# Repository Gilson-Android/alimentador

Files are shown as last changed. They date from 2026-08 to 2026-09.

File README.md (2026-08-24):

# AquaFeeder ESP32-S3

Alimentador automático de aquário com **agenda de horários**, **acionamento manual
de qualquer lugar** e **câmera** para conferir se está tudo bem. Todas as peças
são impressas em 3D e o firmware roda num ESP32-S3.

### 📖 [Guia de montagem](https://gilson-android.github.io/alimentador/) · 🔌 [Referência da API](https://gilson-android.github.io/alimentador/api.html)

O site é o mesmo conteúdo desta documentação, mas navegável, com seletor de motor,
calculadora de dose, checklist de viagem e gerador de comandos da API.

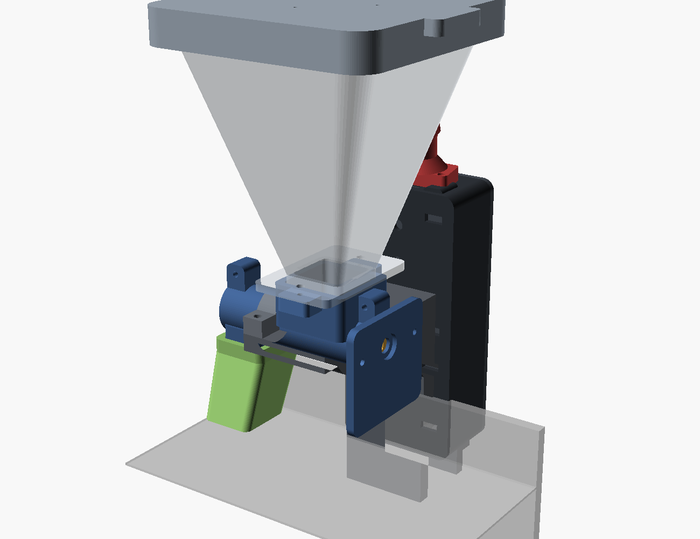
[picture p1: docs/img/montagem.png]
Vista de conjunto


## O que ele faz

| Recurso | Como |
|---|---|
| Agenda | Até 8 horários, dias da semana e porções por horário |
| Alimentar agora | Botão na interface web, comando no Telegram ou o botão BOOT da placa |
| Câmera | Foto sob demanda + vídeo ao vivo (MJPEG) na interface |
| Fora de casa | Bot do Telegram (`/alimentar`, `/foto`, `/status`) — sem abrir porta no roteador |
| Não perde refeição | Se faltar luz na hora marcada, recupera quando voltar (janela configurável) |
| Anti-entupimento | Recua a rosca antes de cada dose; sensor de grãos opcional avisa se nada caiu |
| Trava de segurança | Limite de porções por dia, por acionamento e intervalo mínimo |
| Atualização | OTA pela rede depois da primeira gravação |

## Como funciona a mecânica

Funil de ~300 ml → **rosca sem-fim (auger)** girada por um motor de passo
28BYJ-48 → a ração cai por uma calha inclinada acima da água.

Rosca sem-fim é o mecanismo certo aqui: a dose é proporcional ao ângulo de giro
(dá para dosar 0,2 ml), o tubo cheio de ração veda a passagem de umidade, e o
motor de passo trava sozinho quando parado. Uma volta completa entrega ~0,9 ml;
a porção padrão é **1/4 de volta ≈ 0,23 ml**, ajustável na interface.

> A rosca funciona muito bem com **ração granulada/peletizada de até ~3 mm**.
> Com ração em flocos grandes ela pode enroscar — quebre os flocos ou use
> granulado. Ver [docs/05-calibracao.md](docs/05-calibracao.md).

## Ver o projeto montado em 3D

Dois arquivos servem só para você olhar (**não são para imprimir**):

- `stl/montagem_completa.stl` — o conjunto inteiro já montado
- `stl/montagem_explodida.stl` — as peças separadas, para entender a ordem de montagem

Abra do jeito que preferir:

- duplo clique no Windows → abre no **Visualizador 3D**;
- arraste para o **Creality Print** (ou qualquer fatiador);
- ou jogue em https://viewstl.com, sem instalar nada.

Para girar as peças, esconder o funil, ver em corte ou explodido, abra
`cad/assembly.scad` no OpenSCAD e mexa nas chaves do topo do arquivo
(`CUTAWAY`, `EXPLODE`, `SHOW_HOPPER`, `SHOW_BOX`, `SHOW_TANK`).

| | |
|---|---|
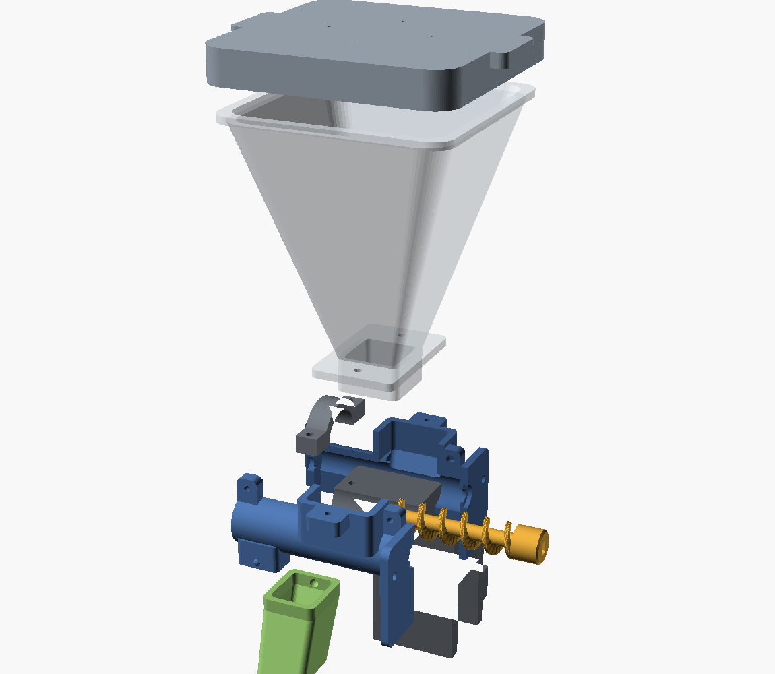
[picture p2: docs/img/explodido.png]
explodido
| montado |  |
| Montado no aquário | Explodido |
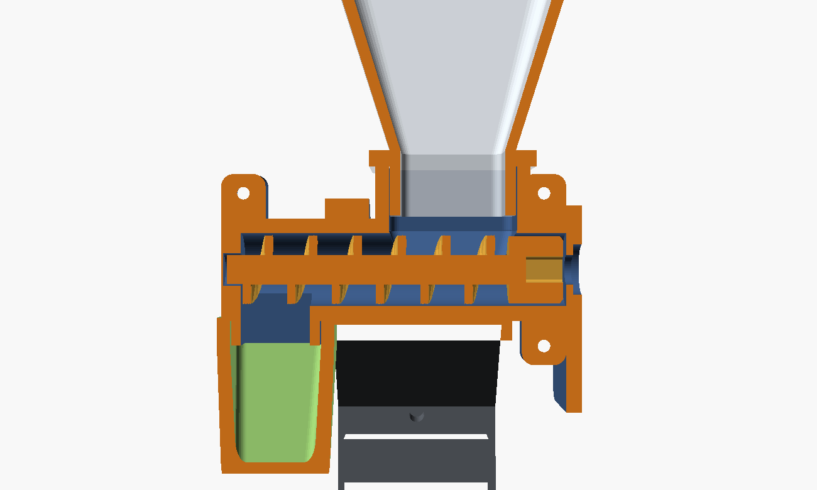
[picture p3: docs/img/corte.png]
corte
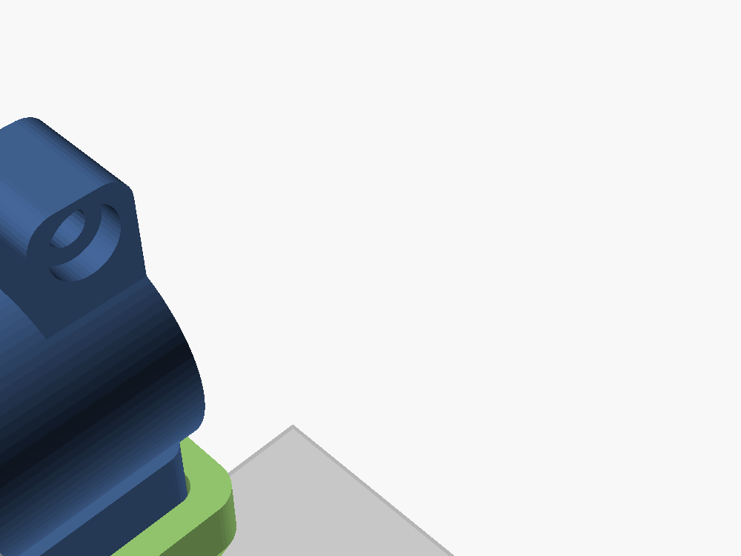
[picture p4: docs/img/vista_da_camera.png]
camera
|  |  |
| Corte no meio do tubo | O que a câmera enquadra |

## Lista de compras

| Item | Qtd | Preço aprox. (BRL) |
|---|---|---|
| Placa ESP32-S3 **com câmera** (kit Freenove ESP32-S3-WROOM CAM) | 1 | 90–170 |
| Motor 28BYJ-48 5 V + driver ULN2003 | 1 | 15–30 |
| Fonte 5 V / 2 A (ou carregador USB 5 V 2 A + cabo) | 1 | 25–45 |
| Capacitor eletrolítico 470–1000 µF / 10 V ou 16 V | 1 | 2 |
| Cabo 4 vias / jumpers fêmea-fêmea | ~1 m | 10 |
| Parafusos M3×8 (3), M3×10 (8), M3×12 (2), M3×16 (2), M4×12 (2), M2×6 (2) | — | 15 |
| Parafuso M4×30 + porca M4 (aperto da braçadeira) | 1 | 3 |
| Filamento **PETG** | ~270 g | 22 |
| *Opcional:* sensor óptico TCRT5000 ou par IR (confirma que caiu ração) | 1 | 8 |
| *Opcional:* sachê de sílica gel (anti-umidade dentro do funil) | 1 | 2 |

Total: **~R$ 190 a 300**, dependendo da placa.

Alternativas de placa que o firmware já suporta: **XIAO ESP32S3 Sense**
(menorzinha, câmera embutida) e **qualquer ESP32-S3 sem câmera** (compila com
`-e s3_sem_camera`).

## Ordem de execução

**Comece pelo [roteiro das 9 etapas](docs/00-etapas.md).** Ele é a ordem de
execução com um teste objetivo no fim de cada etapa — não passe para a próxima
sem o visto. A câmera é a última de propósito: é a única parte que, se não
funcionar, não impede o alimentador de alimentar.

Os arquivos abaixo são a referência por assunto, para consultar dentro de cada etapa:

1. **[Imprimir](docs/01-impressao.md)** — comece pela peça de teste (`peca_de_teste.stl`, ~10 min).
   Só depois imprima o resto.
2. **[Eletrônica](docs/02-eletronica.md)** — 6 fios, nada de solda obrigatória.
3. **[Montagem](docs/03-montagem.md)** — parafusar as duas metades do tubo, funil, calha, braçadeira.
4. **[Firmware](docs/04-firmware.md)** — gravar, conectar no Wi-Fi, definir senha.
5. **[Calibração](docs/05-calibracao.md)** — descobrir quantos passos = a porção do *seu* peixe.
6. **[Telegram / acesso remoto](docs/06-remoto.md)** — para usar de fora de casa.
7. **[Antes de viajar](docs/07-antes-de-viajar.md)** — checklist. Leia mesmo.

Deu problema? **[docs/08-problemas.md](docs/08-problemas.md)** tem os sintomas
mais comuns (rosca travando, reset ao alimentar, câmera não inicializa,
horário errado) com a causa e a solução de cada um.

## Estrutura do projeto

```
Alimentador/
├── index.html      guia de montagem (GitHub Pages)
├── api.html        referência da API HTTP
├── cad/            fontes OpenSCAD (paramétricas) + build.sh
├── stl/            STLs prontos para fatiar
│   ├── motor_28byj/    tubo + rosca para o 28BYJ-48
│   └── motor_nema17/   tubo + rosca para o NEMA 17
├── firmware/
│   ├── src/ include/   código C++ (PlatformIO)
│   └── bin/            binários já compilados
└── docs/           documentação em markdown + imagens
```

O firmware compila limpo em todos os ambientes (testado): RAM 17%, Flash 32%.

**CI:** `azure-pipelines.yml` compila o firmware nos 5 ambientes e renderiza todas
as peças no OpenSCAD a cada push — qualquer warning do OpenSCAD reprova o build.
Os `.bin` e os `.stl` saem como artefato. Para ligar: Azure DevOps → Pipelines →
New pipeline → GitHub → *Existing YAML* → `/azure-pipelines.yml`.

**Relatório das peças:** `python cad/dims.py` lista dimensões, volume e massa
estimada em PETG de cada peça, com o total por kit.

**Teste de encaixe:** `cad/check.sh` renderiza a interseção de cada par de peças
na posição de montagem e mede o volume. Volume zero = as peças só se tocam
(apoio, encaixe). Volume maior que zero = ocupam o mesmo espaço e não montam.
Foi assim que apareceram duas colisões que passavam batido no olho: as orelhas
do colar contra o chanfro do funil, e a calha batendo 0,6 mm na barriga do tubo.

Para mudar qualquer medida, edite `cad/common.scad` e rode `cad/build.sh` —
todos os STLs são regerados. Precisa do [OpenSCAD](https://openscad.org) instalado.

## Avisos importantes

- **Comida em excesso mata mais peixe que fome.** A maioria dos peixes
  tropicais adultos passa 5–7 dias sem comer sem problema nenhum. Prefira
  errar para baixo. A trava de porções/dia existe por isso.
- Teste o conjunto **por uma semana inteira** antes de depender dele numa viagem.
- Eletrônica fica **do lado de fora do aquário**, com laço de gotejamento no
  cabo. Nunca use fonte de mais de 5 V nem passe cabo por dentro da água.
- Ração absorve umidade e empedra: sachê de sílica no funil e tampa sempre fechada.

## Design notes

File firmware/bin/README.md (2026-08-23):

# Binários já compilados

Gerados com PlatformIO (espressif32 6.9.x / Arduino core 2.0.17) a partir do
código em `../src`. Servem para gravar sem instalar toolchain nenhum.

| Pasta | Placa |
|---|---|
| `freenove_s3_cam` | Freenove ESP32-S3-WROOM CAM (8 MB flash) — padrão |
| `xiao_s3_sense` | Seeed XIAO ESP32S3 Sense |
| `s3_sem_camera` | ESP32-S3 genérico, sem câmera |

O caminho recomendado continua sendo `pio run -t upload`
(ver [docs/04-firmware.md](../../docs/04-firmware.md)). Para gravar direto com esptool:

```bash
pip install esptool
cd freenove_s3_cam
esptool.py --chip esp32s3 --port COM5 --baud 921600 write_flash -z 0x0 bootloader.bin 0x8000 partitions.bin 0xe000 boot_app0.bin 0x10000 firmware.bin
```

Troque `COM5` pela porta da sua placa. Se der erro de conexão, ponha a placa em
modo download: segure BOOT, toque RESET, solte BOOT.

Depois de gravado, a configuração é toda pela interface web (modo AP no primeiro
boot: rede `AquaFeeder-XXXX`, senha `aquafeeder`, http://192.168.4.1).

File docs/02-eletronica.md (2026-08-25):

# 2. Eletrônica

> **Esquema visual colorido:** [guia no site → Eletrônica](https://gilson-android.github.io/alimentador/#eletronica).
> Lá tem o diagrama de ligação desenhado, com as cores de cada fio. Este arquivo é
> a versão em texto, para consultar offline.

O projeto suporta dois motores. Escolha a sua seção.

---

## Opção A — 28BYJ-48 + ULN2003 (5 V)

São 6 fios. Não precisa soldar nada se usar jumpers fêmea-fêmea.

```
      FONTE 5V 2A
        +5V  ────────────┬──────────────┬─────────┐
                         │              │         │
        GND  ────────┬───┼──────────┬───┼─────────┼──┐
                     │   │          │   │         │  │
                  ESP32-S3        ULN2003      C1 470–1000uF
                  5V   GND        5V   GND     (+)      (−)

   ESP32-S3 GPIO 1  ──────────────►  IN1   ULN2003
   ESP32-S3 GPIO 2  ──────────────►  IN2
   ESP32-S3 GPIO 41 ──────────────►  IN3
   ESP32-S3 GPIO 42 ──────────────►  IN4

   ULN2003 (conector branco 5 vias) ──► motor 28BYJ-48
   Câmera OV2640 ──► conector flat da própria placa
```

| ULN2003 | ESP32-S3 | Por quê |
|---|---|---|
| IN1 | GPIO 1 | |
| IN2 | GPIO 2 | |
| IN3 | GPIO 41 | |
| IN4 | GPIO 42 | |
| 5 V | +5 V da fonte | motor puxa até ~500 mA, não tire do 3V3 |
| GND | GND comum | **o GND da fonte, do ESP32 e do driver tem que ser o mesmo** |

Compile com `pio run -e freenove_s3_cam -t upload`.

---

## Opção B — NEMA 17 + DRV8825 (12 V)

```
   FONTE 12V ──┬── VMOT (driver) ── C 100uF entre VMOT e GND
               └── step-down 5V ──► ESP32-S3 (pino 5V)

   GND da fonte ──► GND do ESP32 ──► GND do driver   (tudo no mesmo GND)

   ESP32 GPIO 1  ──► STP         M0 ──┐
   ESP32 GPIO 2  ──► DIR         M1 ──┴─► 3V3   (1/8 de micropasso)
   ESP32 GPIO 41 ──► EN          M2 ────► GND
   ESP32 3V3     ──► RST + SLP
   1A + 2A ──► uma bobina do motor   (pinos vizinhos na placa)
   1B + 2B ──► a outra bobina
```

Os nomes abaixo são os da **serigrafia da placa** (o clone roxo da Pololu):

| Pino (serigrafia) | Ligar em | Observação |
|---|---|---|
| **STP** | GPIO 1 | é o STEP |
| **DIR** | GPIO 2 | |
| **EN** | GPIO 41 | ativo em nível baixo; o firmware solta o motor quando para |
| **M0**, **M1** | 3V3 do ESP32 | M2=0 M1=1 M0=1 → **1/8 de micropasso** |
| **M2** | GND | idem |
| **RST**, **SLP** | 3V3 do ESP32 | os dois; sem isso o driver fica em reset |
| **VMOT** + o **GND** vizinho | +12 V da fonte | **100 µF eletrolítico direto nesses dois pinos** |
| **GND** (o outro) | GND comum | mesmo GND do ESP32 e da fonte |
| **1A** + **2A** | uma bobina do motor | os dois pinos de cada bobina são **vizinhos** na placa |
| **1B** + **2B** | a outra bobina | |
| **FLT** | — | é o FAULT; deixe solto |

Os 4 pinos de motor ficam no meio daquela fileira, entre o par `VMOT`/`GND` e o
par `FLT`/`GND`. **Contando a partir do lado do `VMOT`**, a ordem é:

```
VMOT · GND · 2B · 1B · 1A · 2A · FLT · GND
              └──┬──┘   └──┬──┘
              bobina 1  bobina 2
```

Os dois pinos de cada bobina são vizinhos — é isso que faz o plugue do cabo
encaixar direto.

**O DRV8825 não tem pino VDD.** Diferente do A4988, ele gera a lógica dele
internamente a partir do VMOT — não existe fio de 3,3 V *alimentando* o driver. O
3V3 do ESP32 serve só para puxar M0, M1, RST e SLP para nível alto. Consequência:
**sem os 12 V o driver está morto**, mesmo com o ESP32 ligado.

### Limite de corrente — faça antes de ligar o motor

Com o motor **desconectado** e os 12 V ligados, meça a tensão entre o cursor do
trimpot e o GND:

- **DRV8825:** `Vref = corrente ÷ 2` → **0,25 V para 0,5 A**
- A4988: `Vref = corrente × 0,8` → 0,4 V para 0,5 A

0,4 a 0,6 A é mais que suficiente para a rosca e mantém o driver frio.

### O cabo que vem com o motor já resolve os pares

Os cabos de motor de impressora **trocam a ordem dos fios entre as duas pontas**,
de propósito:

| Ponta | Ordem | Pares |
|---|---|---|
| no motor (JST) | vermelho · preto · azul · verde | intercalados |
| no driver (plugue 4 vias) | vermelho · azul · verde · preto | **vizinhos** |

Como os 4 pinos de motor do DRV8825 também são vizinhos por par (`2B`+`1B` e
`1A`+`2A`), o plugue **encaixa direto nos 4 pinos em sequência**, sem separar fio
nenhum.

E tanto faz a orientação: plugado virado 180° os pares continuam certos (só troca
qual bobina é qual). A única diferença é o sentido de giro da rosca, que se
corrige em *Ajustes → Dosagem → Inverter sentido*, sem mexer em fio.

### Se o seu cabo for outro: achar os pares

Multímetro em continuidade (ou ohms) e toque dois fios do motor por vez. O par que
apitar — ou marcar 2 a 4 Ω — é uma bobina, e vai em **1A + 2A**. O outro par vai em
**1B + 2B**.

Em motor de impressora com fios **vermelho / preto / azul / verde**, o mais comum é
**preto + verde** numa bobina e **vermelho + azul** na outra. Mas clone é clone: meça.

Se o motor vibrar no lugar sem girar, você misturou os pares — troque **2A** com **1B**.

### Outros drivers

| Driver | Micropasso 1/8 | Precisa de VDD? |
|---|---|---|
| DRV8825 | M0=H, M1=H, M2=L | não |
| A4988 | MS1=H, MS2=H, MS3=L | **sim**, 3V3 |
| TMC2208/2209 | MS1=L, MS2=L (padrão) | sim, 3V3 |

Compile com `pio run -e freenove_s3_cam_nema17 -t upload`.

O DRV8825 esquenta: deixe o dissipador virado para as fendas de ventilação da
caixa e não encoste nada nele. O step-down também aquece — mantenha os dois
separados.

---

## O capacitor não é opcional (vale para os dois motores)

O motor de passo dá picos de corrente a cada passo. Sem o eletrolítico ligado
entre a alimentação e o GND **junto do driver**, o pico derruba a tensão e você
vê: câmera falhando ao inicializar, reset aleatório, Wi-Fi caindo exatamente na
hora de alimentar. Respeite a polaridade — a faixa clara no corpo marca o
negativo.

- 28BYJ-48 / ULN2003: **470–1000 µF** entre 5 V e GND
- NEMA 17 / DRV8825: **100 µF** entre VMOT e GND

## Ligar o OV2640 na mão (placa sem conector de flat)

Se a sua placa é uma **ESP32-S3-DevKitC-1 / YD-ESP32-S3** (módulo N16R8, por
exemplo), ela não tem o conector de 24 vias. Dá para usar um módulo OV2640
avulso ligando 14 fios no header. Os pinos abaixo são **exatamente** os que o
firmware já espera (`FEEDER_BOARD=1`), então não precisa mexer em código:

| Módulo OV2640 | ESP32-S3 | | Módulo OV2640 | ESP32-S3 |
|---|---|---|---|---|
| `SIOD` / SDA | GPIO 4 | | `D0` / Y2 | GPIO 11 |
| `SIOC` / SCL | GPIO 5 | | `D1` / Y3 | GPIO 9 |
| `VSYNC` | GPIO 6 | | `D2` / Y4 | GPIO 8 |
| `HREF` | GPIO 7 | | `D3` / Y5 | GPIO 10 |
| `PCLK` | GPIO 13 | | `D4` / Y6 | GPIO 12 |
| `XCLK` | GPIO 15 | | `D5` / Y7 | GPIO 18 |
| `3V3` | 3V3 | | `D6` / Y8 | GPIO 17 |
| `GND` | GND | | `D7` / Y9 | GPIO 16 |

`PWDN` e `RESET` ficam sem ligar.

**O barramento é paralelo a 20 MHz — fio comprido não perdoa.** Regras:

- fios de no máximo **10 cm**, de preferência 5;
- mantenha os 8 fios de dados juntos e o `GND` junto deles;
- não passe o cabo do motor em paralelo com esses fios;
- imagem listrada, verde ou "chuviscada" = ruído no barramento. Antes de
  desistir, compile com `-DCAM_XCLK_HZ=10000000` (metade do clock). Resolve na
  maioria dos casos, com pequena perda de taxa de quadros.

Se ficar muito ruim, o plano B é a **URL de câmera externa** em
*Ajustes → Câmera* — um celular velho com o app *IP Webcam* dá imagem melhor
que qualquer OV2640, sem fio nenhum.

Compile com `pio run -e devkitc_s3_n16r8_nema17 -t upload`.

## Sensor de grãos (opcional, mas recomendado para viagem)

Confirma que a ração realmente caiu. Sem ele, o alimentador "acha" que alimentou
mesmo se a rosca estiver travada ou o funil vazio.

- Imprima a calha na variante **`calha_com_sensor.stl`**: ela tem dois furos de
  3,4 mm alinhados, um de cada lado do duto. Encaixe por pressão um **LED IR de
  3 mm** num furo e um **fototransistor de 3 mm** no outro — o feixe atravessa
  o duto e cada grão que passa gera um pulso. (Um módulo **TCRT5000**
  reflexivo, com os 3 pinos VCC/GND/D0, também funciona: aponte para o furo.)
- Alimente com **3,3 V** (não 5 V — a entrada do ESP32 não é 5 V tolerante).
  Com LED+fototransistor discretos: resistor de 150 Ω em série no LED e
  10 kΩ do coletor para 3,3 V.
- Saída digital → **GPIO 21**.
- Ligue em *Ajustes → Sensor de grãos* e **reinicie** o aparelho.

Se o sensor estiver ligado e nenhum grão for detectado, o firmware recua a
rosca, tenta de novo e — se ainda nada — registra falha no histórico e manda
aviso no Telegram.

## Alimentação

**28BYJ-48:** um carregador de celular de 5 V / 2 A resolve. Ligue placa e driver
na mesma fonte, em paralelo, com fio de 22 AWG ou mais grosso.

**NEMA 17:** fonte de 12 V / 2 A + um step-down (MP1584 ou LM2596) para tirar os
5 V do ESP32. **Ajuste a saída do step-down para 5,0 V antes de ligar na placa** —
esses módulos saem de fábrica em qualquer tensão.

**Alternativa mais simples (sem step-down):** alimente o **ESP32 por um carregador
USB de parede** (5 V) e use a fonte de 12 V **só para o driver** (VMOT). A única
exigência é **unir os GNDs**: o GND da fonte de 12 V tem que estar ligado ao GND do
ESP32, senão o driver não lê os sinais STEP/DIR/EN e o motor não gira. Use carregador
de parede, não powerbank.

Não use powerbank como fonte fixa: muitos desligam sozinhos quando o consumo cai
(o alimentador fica em repouso a maior parte do tempo).

**Nobreak:** se sua região tem queda de luz frequente, vale plugar a fonte num
nobreak pequeno. Mas o firmware já recupera o horário perdido quando a energia
volta — veja `catchUpMin` em Ajustes.

## Montagem dentro da caixa

A caixa (`caixa_eletronica.stl`) tem:

- pinos para a placa ESP32-S3 (esquerda) e para o driver (direita) — para
  parafuso auto-atarraxante M2,5;
- **fendas de abraçadeira** como plano B: se os furos da sua placa não baterem
  com os pinos, prenda com abraçadeira de nylon ou fita dupla face e ignore os pinos;
- janela para o USB-C numa das pontas (essa ponta fica para **cima** na montagem);
- dois furos de 7,5 mm na outra ponta para os cabos saírem **para baixo**;
- 2 furos de 4,5 mm no fundo para parafusar no mastro da braçadeira.

> **Confira com paquímetro** a distância entre os furos da sua placa e ajuste
> `b1_hx` / `b1_hy` em `cad/common.scad` antes de imprimir a caixa. Os valores
> padrão (55 × 20 mm) são para a placa Freenove.

**Laço de gotejamento:** deixe os cabos saírem pela parte de baixo da caixa e
subirem em curva até o motor. Se um dia escorrer água pelo cabo, ela pinga no
chão em vez de entrar na caixa.

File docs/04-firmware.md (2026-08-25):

# 4. Firmware

## Gravar (PlatformIO — recomendado)

Instale o [VS Code](https://code.visualstudio.com) + extensão **PlatformIO IDE**,
abra a pasta `firmware/` e clique em *Upload*. Ou por linha de comando:

```bash
pip install --user platformio
cd firmware
pio run -e freenove_s3_cam -t upload
pio device monitor
```

Ambientes disponíveis (o `-e`):

| Ambiente | Placa |
|---|---|
| `freenove_s3_cam` | Freenove ESP32-S3-WROOM CAM (padrão) |
| `xiao_s3_sense` | Seeed XIAO ESP32S3 Sense |
| `devkitc_s3_n16r8` | ESP32-S3-DevKitC-1 / YD-ESP32-S3, módulo N16R8 |
| `s3_sem_camera` | qualquer ESP32-S3 sem câmera |

Cada um desses tem uma variante `_nema17` (ex.: `freenove_s3_cam_nema17`) para
quem usa NEMA 17 + driver STEP/DIR em vez do 28BYJ-48.

**Placa Freenove:** grave pela porta **UART** (a que tem o chip USB-serial), não
pela USB nativa. É onde o log serial aparece também. Se a gravação falhar,
segure BOOT, dê um toque em RESET, solte BOOT e tente de novo.

**Trocar de pinos?** Está tudo em `firmware/include/config.h`.

## Primeiro boot

Não há Wi-Fi salvo, então o aparelho sobe em **modo configuração**:

1. Procure a rede Wi-Fi **`AquaFeeder-XXXX`** e conecte com a senha `aquafeeder`.
2. Abra **http://192.168.4.1**.
3. Vá em *Ajustes → Rede e sistema*, toque em **Procurar redes 2,4 GHz** e escolha
   o seu Wi-Fi na lista (só aparecem redes de 2,4 GHz, as únicas que o ESP32 usa),
   digite a senha, **defina uma senha para a interface** e salve. O aparelho
   reinicia e entra na sua rede.
4. Depois disso, acesse por **http://aquafeeder.local** (ou pelo IP que aparece
   no monitor serial / na lista de dispositivos do seu roteador).

Vale **reservar o IP** (DHCP estático) no roteador — assim o endereço nunca muda.

Uma vez configurado, o aparelho **nunca mais volta ao modo `AquaFeeder-XXXX`**: se a
rede cair ou faltar luz, ele segue tentando reconectar em segundo plano (a agenda
continua rodando com o relógio interno) e reentra na sua rede sozinho quando o Wi-Fi
volta.

## A interface

Quatro abas:

- **Agora** — porções do dia, última alimentação, botões de 1/2/3 porções, foto
  e vídeo da câmera, e o controle de manutenção da rosca (avançar/recuar).
- **Agenda** — 8 horários. Cada linha: liga/desliga, hora, porções e os dias da
  semana (D S T Q Q S S). Não esqueça de *Salvar agenda*.
- **Ajustes** — dosagem, travas de segurança, câmera, Telegram, rede.
  Em *Câmera* existe o campo **URL de câmera externa**: se você não tem um módulo
  OV2640, cole ali o endereço de qualquer fonte MJPEG/JPEG (celular velho com o app
  *IP Webcam*, câmera Wi-Fi) e a aba *Agora* passa a mostrar essa imagem. O
  navegador busca a URL direto; o ESP32 não faz proxy e não gasta memória com isso.
- **Histórico** — as últimas 24 alimentações, com origem (agenda, manual,
  telegram, botão) e quantos grãos o sensor contou.

## Atualizações depois da primeira gravação

Funciona OTA pela rede:

```bash
pio run -e freenove_s3_cam -t upload --upload-port aquafeeder.local
```

A senha do OTA é a mesma senha da interface.

## API HTTP

Tudo que a interface faz está exposto — dá para automatizar (n8n, Home
Assistant, cron, script). Autenticação por cookie de sessão:

```bash
# login (guarda o cookie)
curl -c ck.txt -X POST http://aquafeeder.local/api/login \
     -d '{"pass":"SUA_SENHA"}'

# estado
curl -b ck.txt http://aquafeeder.local/api/status

# alimentar 2 porções
curl -b ck.txt -X POST "http://aquafeeder.local/api/feed?p=2"

# histórico
curl -b ck.txt http://aquafeeder.local/api/log

# foto
curl -b ck.txt http://aquafeeder.local/snapshot.jpg -o aquario.jpg
```

| Método | Rota | O que faz |
|---|---|---|
| GET | `/` | interface |
| POST | `/api/login` | `{"pass":"..."}` → cookie de sessão |
| GET | `/api/status` | estado geral |
| GET/POST | `/api/config` | lê / grava configuração e agenda |
| POST | `/api/feed?p=N` | alimenta N porções (respeita as travas) |
| POST | `/api/jog?s=N` | gira N meio-passos (negativo = recua) |
| GET | `/api/log` | últimas alimentações |
| POST | `/api/reboot` | reinicia |
| GET | `/snapshot.jpg` | foto JPEG |
| GET | `:81/stream` | vídeo MJPEG (porta 81) |

Erros vêm como `{"err":"mensagem"}` com HTTP 400/401/429.

## Como a agenda decide alimentar

A cada 15 s o firmware avalia cada horário ativo:

```
disparar se:  já passou da hora  E
              a última alimentação foi ANTES dessa hora  E
              não passou mais que "janela de recuperação" minutos
```

Consequências práticas (todas desejáveis):

- Faltou luz às 08:00 e voltou às 08:40 → **alimenta ao ligar** (dentro da janela de 90 min).
- Faltou luz às 08:00 e voltou às 14:00 → **não alimenta**, ficou fora da janela.
- Você alimentou na mão às 07:50 → o horário das 08:00 **é pulado** (já comeram).
- Reset/reboot no meio do dia → não repete refeições já feitas.

O contador do dia e a hora da última refeição ficam gravados na memória
permanente (NVS), então sobrevivem a falta de energia.

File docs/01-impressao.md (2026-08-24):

# 1. Impressão (Creality K1 Max)

## Material

**PETG.** Ração e água = umidade e respingo; PETG não empena com calor, aguenta
melhor umidade e é mais tenaz que PLA nas roscas dos parafusos.
PLA funciona, mas evite deixar exposto ao sol e não conte com ele por anos.

| Parâmetro | PETG na K1 Max |
|---|---|
| Bico / camada | 0.4 mm / **0.2 mm** |
| Bico | 240–250 °C |
| Mesa | 80 °C |
| Velocidade | 60–120 mm/s (não force PETG a 300 mm/s) |
| Ventilação | 40–60 % |
| Paredes | **3** (4 no tubo) |
| Preenchimento | 20 % (30 % na rosca) |
| Suporte | só o funil precisa (ver abaixo) |
| Retração / “combing” | ligue “evitar cruzar contornos” para reduzir fio de PETG |

Todos os STLs já saem na orientação correta de impressão. **Não gire as peças
no fatiador** — a orientação foi escolhida para minimizar saliência e deixar as
camadas na direção certa dos esforços.

## Suporte: liga em UMA peça e desliga em todas as outras

| Peça | Suporte | Por quê |
|---|---|---|
| `funil.stl` | **LIGA** | o flange é uma aba de 3,2 mm que salta 13 mm do pescoço, a 10 mm da mesa. São ~1100 mm² de área plana virada para baixo. Suporte fácil de tirar |
| `tubo_metade_a/b.stl` | **NUNCA LIGA** | o suporte iria para **dentro** do furo de 15 mm e para dentro do socket do funil, e você não tira mais |
| todas as outras | não precisa | orientação escolhida para não ter saliência |

As metades do tubo têm ~1380 mm² virados para baixo, mas são **pontes entre
paredes**, não ilhas:

- o teto do furo interno (é por isso que a folga da rosca é 0,6 mm — para
  engolir a barriga que a ponte deixa);
- o teto do socket do funil, uma ponte plana de 26 mm.

PETG faz ponte de 26 mm sem drama. Ligar suporte aí só cria um problema novo:
plástico preso dentro do tubo, no caminho da rosca.

No Creality Print dá para ligar suporte **por objeto**: selecione só o funil e
marque suporte nele.

## Imprima PRIMEIRO a peça de teste

```
stl/motor_28byj/peca_de_teste.stl     ~10 min,  9 g
stl/motor_nema17/peca_de_teste.stl    ~14 min, 12 g
```

Só a do **seu** motor.

Ela tem quatro gabaritos:

1. **Furos do motor 28BYJ-48** — parafuse o motor de verdade nela, com M3 × 10.
   Os furos têm 2,6 mm (o M3 rosqueia direto no plástico, sem porca), 35 mm entre
   centros, e há um rebaixo para o ressalto do eixo. Se o seu motor for um clone
   com outra medida, corrija `m_hole_pitch` / `m_boss_d` em `cad/common.scad`.
2. **Encaixe do eixo achatado** — enfie o eixo do motor. Deve entrar com
   pressão firme dos dedos, sem folga de giro.
3. **Socket do funil** + 4. **amostra do funil** — devem encaixar com atrito,
   sem forçar.

Se estiver **apertado demais**: abra `cad/common.scad`, mude `fit = 0.10` (ou `0.15`),
rode `cad/build.sh` e reimprima só a peça de teste.
Se estiver **frouxo**: use `fit = -0.10`.
Só depois disso imprima o resto — economiza umas 15 horas de retrabalho.

## Lista de peças

As quatro peças que dependem do motor ficam em `stl/motor_28byj/` e
`stl/motor_nema17/`. **Imprima só a pasta do seu motor.**

| Arquivo | Qtd | ~Massa | Observação |
|---|---|---|---|
| `motor_*/rosca.stl` | 1 | 3–4 g | a rosca; imprime em pé, cubo na mesa |
| `motor_*/tubo_metade_a.stl` | 1 | 10–13 g | metade do tubo — **furos roscados** M3 (2,55 mm) |
| `motor_*/tubo_metade_b.stl` | 1 | 10–13 g | metade do tubo — furos passantes 3,3 mm com rebaixo |
| `motor_*/peca_de_teste.stl` | 1 | 9–12 g | **imprima esta primeiro** |
| `funil.stl` | 1 | 65 g | reservatório ~300 ml, sai translúcido; 124 mm de altura |
| `tampa_do_funil.stl` | 1 | 26 g | |
| `calha.stl` | 1 | 6 g | calha de saída |
| `calha_com_sensor.stl` | (alt.) | 6 g | mesma calha, com 2 furos de 3,4 mm para o sensor óptico |
| `bracadeira.stl` | 1 | 66 g | braçadeira + mastro + berço; imprime em pé, 38 mm |
| `tampa_do_berco.stl` | 1 | 2 g | fecha o tubo no berço |
| `manipulo.stl` | 1 | 6 g | manípulo do parafuso de aperto |
| `caixa_eletronica.stl` | 1 | 31 g | |
| `tampa_da_caixa.stl` | 1 | 14 g | |
| `suporte_da_camera.stl` | 1 | 15 g | já com o giro de 45° que desvia do funil |

Total ≈ **256 g** (28BYJ) ou **263 g** (NEMA 17). Cabe tudo em duas mesas na K1 Max (300×300).
Sugestão: mesa 1 = `bracket` + `hopper` + `lid`; mesa 2 = o resto.

## Detalhes que importam

**`rosca.stl` (a rosca)** — imprime em pé. A versão do NEMA 17 tem 81 mm de altura
para 14 mm de diâmetro: **use brim** (5 mm) e velocidade de 40 mm/s, senão ela
descola no meio da impressão. A hélice é uma escada helicoidal:
cada camada apoia na anterior, então sai sem suporte. Se a borda da hélice
ficar “peluda”, baixe a velocidade para 40 mm/s só nessa peça. Depois de
imprimir, passe o dedo na hélice para tirar rebarba — rebarba é a causa nº 1
de rosca travando no tubo.

**`tubo_metade_a` / `tubo_metade_b`** — saem com a face plana na mesa, canal para
cima. A metade **A** tem furos de 2,55 mm (o parafuso M3 rosca direto no
plástico); a **B** tem furos passantes de 3,3 mm com rebaixo para a cabeça. Não
troque.

Com **NEMA 17** o tubo é 13 mm mais longo (o cubo da rosca precisa engolir o eixo
longo do motor) e o prato de fixação é 52 × 52 mm com os 4 furos em quadrado de
31 mm. Fora isso é a mesma peça.

**`bracadeira.stl`** — é um perfil constante extrudado 40 mm: imprime em pé, sem
nenhum overhang. Parece muito material (66 g) porque é a peça que segura ~400 g
pendurados na borda do aquário.

**`funil.stl`** — parede de 2,2 mm com 3 perímetros fica translúcido, o que é
ótimo: você vê o nível da ração. As paredes têm 72° de inclinação para a ração
escorrer sozinha.

Se quiser um funil maior/menor, mude `hop_taper_h` e `hop_top` em
`cad/common.scad` (o socket de baixo precisa continuar com 25,6 mm).

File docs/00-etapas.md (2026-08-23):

# 0. Roteiro — as 9 etapas, nesta ordem

Cada etapa termina num **teste objetivo**. Não passe para a próxima sem o visto:
é assim que você descobre um problema enquanto ele ainda é pequeno e barato.

A câmera é a última de propósito. Ela é a única parte que, se não funcionar,
**não impede o alimentador de alimentar** — e é a que mais dá trabalho. Colocar
ela no começo é o jeito mais rápido de travar o projeto inteiro num detalhe que
não é essencial.

| # | Etapa | Termina quando |
|---|---|---|
| 1 | Peça de teste | os 4 encaixes conferem |
| 2 | Motor girando na bancada | gira suave nos dois sentidos, sem esquentar |
| 3 | Wi-Fi, relógio e senha | `aquafeeder.local` abre e mostra a hora certa |
| 4 | Mecânica seca | a rosca gira livre no tubo, sem ração |
| 5 | Dosagem | 5 doses seguidas com variação ≤ 20% |
| 6 | Montado no aquário | a ração cai na água livre, calha acima do nível |
| 7 | Agenda | 7 dias rodando sozinho, sem sobra no fundo |
| 8 | Acesso remoto | `/status` responde pelo 4G do celular |
| 9 | Câmera | a foto mostra a água e a saída da calha |

---

## Etapa 1 — Peça de teste

**Faz:** imprime `stl/motor_nema17/peca_de_teste.stl` (ou `motor_28byj/`) com o
mesmo filamento e as mesmas configurações que vai usar no resto.

**Visto quando:** o motor parafusa nos 4 furos e assenta plano; o eixo entra no
cilindro deslizando, sem folga de girar; o quadrado menor entra no maior com
atrito de dedo.

**Se falhar:** mexa só em `fit` no `cad/common.scad` (`0.10` afrouxa tudo,
`-0.10` aperta), rode `cad/build.sh` e reimprima **só a peça de teste**.

---

## Etapa 2 — Motor girando na bancada

Ainda **sem nada de mecânica**. Motor solto na mesa.

**Faz:**
1. Liga ESP32 + driver + motor conforme a [seção 2](02-eletronica.md).
2. **Ajusta o Vref com o motor desconectado**: 0,25 V para 0,5 A no DRV8825.
3. Grava: `pio run -e devkitc_s3_n16r8_nema17 -t upload`.
4. Conecta na rede `AquaFeeder-XXXX` (senha `aquafeeder`), abre
   http://192.168.4.1 e usa *Agora → Manutenção → Avançar* e *Recuar*.

**Visto quando:** o eixo gira suave nos dois sentidos, o motor fica só morno e o
driver também. Sem trancos, sem chiado agudo.

**Se falhar:**

| Sintoma | Causa provável |
|---|---|
| vibra no lugar, não gira | pares de bobina trocados — inverta `2A` com `1B` |
| não faz nada | `RST`+`SLP` sem 3V3, ou `VMOT` sem 12 V (o DRV8825 morre sem os 12 V) |
| gira mas trava fácil | Vref baixo demais |
| esquenta muito | Vref alto demais, ou µs por passo pequeno demais |
| ESP reinicia ao girar | falta o capacitor de 100 µF no `VMOT` |

---

## Etapa 3 — Wi-Fi, relógio e senha

**Faz:** em *Ajustes → Rede e sistema*, preenche o seu Wi-Fi, **define uma senha
para a interface** e salva. O aparelho reinicia. Depois reserva o IP dele no
roteador (DHCP estático).

**Visto quando:** `http://aquafeeder.local` abre de outro aparelho da casa **e** o
relógio na aba *Agora* mostra a hora certa.

> Se o relógio mostrar **"sem hora"**, pare aqui: a agenda **não dispara** sem
> relógio sincronizado. Confira o fuso (`<-03>3`) e se a rede tem internet.

---

## Etapa 4 — Mecânica seca

**Faz:** imprime e monta tubo + rosca + funil + calha ([seção 3](03-montagem.md)).
Ainda **sem ração** e **fora do aquário**.

**Visto quando:** você gira o eixo do motor com a mão e a rosca gira livre; no
*Avançar* não há barulho de raspagem; depois de 3 voltas o motor continua morno.

**Se falhar:** rebarba na hélice (lima), parafusos das metades apertados demais
(afrouxe, alinhe pelo giro livre, reaperte), ou barriga no teto do furo do tubo
(raspe com uma lixa enrolada).

---

## Etapa 5 — Dosagem

**Faz:** ração no funil, potinho embaixo da calha, ainda fora do aquário.
Enche a rosca com 3 *Avançar* (jogue essa ração fora), depois clica *1 porção*
cinco vezes e compara.

**Visto quando:** as 5 doses são parecidas — variação de até 20% é normal com
granulado. Ajuste *Ajustes → Passos por porção* até a dose bater com o que seus
peixes limpam em 2–3 minutos.

**Depois:** aperte as travas em *Ajustes → Segurança* (máx./dia justo, não
generoso). Ver [seção 5](05-calibracao.md).

---

## Etapa 6 — Montado no aquário

**Faz:** braçadeira na borda, tubo no berço, caixa no mastro, cabos saindo por
baixo em laço de gotejamento.

**Visto quando:** a saída da calha fica **2 a 5 cm acima da linha d'água**; você
solta 1 porção e a ração cai em **água livre** — não no vidro, não sobre planta,
não em canto onde acumula.

**Se falhar:** ajuste `mast_h` em `cad/bracket.scad` e reimprima só a braçadeira,
ou apoie o conjunto na tampa do aquário com um furo de 25 mm para a calha.

---

## Etapa 7 — Agenda

**Faz:** dois horários na aba *Agenda* e **deixa rodando 7 dias com você em
casa**. No meio da semana, desligue a fonte durante um horário programado e
religue 10 minutos depois.

**Visto quando:** o *Histórico* mostra todos os disparos; **nada sobra no fundo
do aquário**; e o teste de queda de energia alimentou ao voltar.

Este é o único teste que realmente vale. Sem essa semana, você não sabe se o
alimentador funciona — sabe que ele funcionou uma vez.

---

## Etapa 8 — Acesso remoto

**Faz:** Telegram (mais simples) e/ou MQTT (para integrar com outros sistemas).
Ver [seção 6](06-remoto.md).

**Visto quando:** `/status` e `/alimentar` respondem com o celular no **4G**, não
no Wi-Fi de casa. Testar pelo Wi-Fi não prova nada.

**Bônus com MQTT:** o tópico `online` avisa sozinho se o alimentador cair — é o
alarme que faz diferença quando você está longe.

---

## Etapa 9 — Câmera (última)

**Faz:** escolhe um caminho:

1. **Módulo OV2640** ligado nos 14 pinos ([seção 2](02-eletronica.md)) — fios de
   até 10 cm, e se a imagem sair listrada compile com `-DCAM_XCLK_HZ=10000000`.
2. **Celular velho** com o app *IP Webcam*, e a URL em *Ajustes → Câmera →
   Câmera externa*. Sem fio, imagem melhor.

**Visto quando:** a foto na aba *Agora* mostra a **superfície da água** e a
**saída da calha** no mesmo quadro. É esse enquadramento que serve para
diagnosticar de longe: você vê se caiu ração e se a água está boa.

**Se falhar:** o alimentador continua funcionando. Câmera é conforto, não
requisito — e existe o plano B do celular.

---

## Antes de viajar

Com as 9 etapas fechadas, vá para o [checklist de viagem](07-antes-de-viajar.md).
Ele cobre o que fazer nas duas semanas, na semana e no dia anterior — e o plano B
com uma pessoa de confiança.

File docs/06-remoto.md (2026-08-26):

# 6. Usar de fora de casa

A interface web só existe dentro da sua rede. Para acionar de outro lugar você
tem quatro caminhos — em ordem de recomendação:

## Opção 1 — Telegram (mais simples e mais segura)

Não precisa abrir nada no roteador: é o alimentador que sai para conversar com
o Telegram. Funciona de qualquer lugar do mundo, no celular que você já usa.

### Criar o bot

1. No Telegram, fale com **@BotFather** → `/newbot` → escolha um nome.
2. Ele devolve um token tipo `7891234567:AAE...`. **Esse token é a chave da sua
   casa** — não compartilhe, não poste em fórum.
3. Cole em *Ajustes → Telegram → Token do bot* e salve.
4. Mande qualquer mensagem para o seu bot. Ele responde com o seu **chat id**.
5. Cole esse número em *Ajustes → Telegram → Chat ID autorizado* e salve.

Pronto. Só esse chat id consegue dar comandos; qualquer outra pessoa que
encontre o bot é ignorada.

### Botões (o "app" no celular)

Mande **`/start`** (ou `/menu`) para o seu bot uma vez. Ele fixa um teclado de
botões na conversa — `🐟 Alimentar`, `🐟 Alimentar 2x`, `📷 Foto`, `📊 Status`,
`📅 Agenda` — que fica sempre disponível. A partir daí é só tocar, sem digitar
nada. É a forma mais simples de ter um "app" no celular: o app é o próprio
Telegram, funciona de qualquer lugar e não exige hospedar nem configurar nada.

### Comandos

Os botões apenas disparam estes comandos; você também pode digitá-los:

| Comando | O que faz |
|---|---|
| `/menu` | mostra os botões |
| `/alimentar` | 1 porção |
| `/alimentar 2` | 2 porções |
| `/foto` | tira e envia uma foto do aquário |
| `/status` | porções do dia, última refeição, sinal do Wi-Fi |
| `/jog [passos]` | gira a rosca (+ avança, − recua) para desentupir/reencher |
| `/agenda` | lista os horários programados |

### Painel bonito (Telegram Mini App) — opcional

Se quiser uma interface gráfica no lugar dos botões de texto, o projeto traz um
**painel** (pasta `painel/`) que abre DENTRO do Telegram: stepper de porções, botão
grande de alimentar, e atalhos de foto/status/agenda/manutenção. Continua tudo pelo
Telegram — sem broker, sem MQTT, sem nada rodando em servidor.

Como o painel manda os comandos de volta pro bot (via `web_app_data`), as respostas
(status, foto, agenda) chegam como mensagem no chat, e o painel fecha ao enviar.

**Para ligar (uma vez):**

1. **Hospede a pasta `painel/`** num HTTPS. Seu repositório já está no GitHub, então
   o mais simples é o **GitHub Pages**: em *Settings → Pages*, escolha a branch `main`
   e pasta `/ (root)`. A URL fica tipo
   `https://gilson-android.github.io/alimentador/painel/`.
   (Alternativas: arrastar a pasta no **Netlify Drop** ou **Cloudflare Pages**.)
2. **Cole a URL** em `firmware/include/config.h`, na linha
   `#define TG_WEBAPP_URL ""` → ponha a sua URL https entre as aspas.
3. **Recompile e grave** o firmware (`pio run -e SEU_ENV -t upload`).
4. Mande **`/menu`** pro bot: agora aparece o botão **🐟 Abrir painel**.

Deixando `TG_WEBAPP_URL` vazio, o painel some e ficam só os botões de texto — os dois
convivem numa boa. O Telegram exige **https**; `http` ele recusa.

Com *Avisar a cada alimentação* ligado, você recebe uma mensagem a cada
refeição (inclusive as da agenda) — e um alerta se o sensor de grãos não
detectar ração caindo.

**Sobre segurança:** a conexão com o Telegram é HTTPS, mas o firmware **não
valida o certificado** (`setInsecure()`) para economizar memória — é o que
praticamente toda biblioteca de bot para ESP32 faz. O risco real é baixo (só
alguém já dentro da sua rede poderia se passar pelo Telegram), mas está dito.

## Opção 2 — MQTT (para integrar com outros sistemas)

Se você quer comandar de fora do celular (n8n, Home Assistant, Power Automate,
script), use MQTT. O ESP32 conecta **para fora** no broker e fica escutando
`aquafeeder/cmd` — nenhuma porta aberta no roteador.

Configure em *Ajustes → MQTT*: broker, porta, usuário, senha e prefixo. Broker
vazio desliga. Funciona com qualquer broker padrão; HiveMQ Cloud e EMQX
Serverless têm plano free com TLS, e Mosquitto em casa roda sem TLS na 1883.

| Tópico | Direção | Conteúdo |
|---|---|---|
| `aquafeeder/cmd` | você → aparelho | `feed 2`, `jog -800`, `status`, `reboot` (ou JSON) |
| `aquafeeder/online` | aparelho → você | `1`/`0` retido — o `0` vem do **broker** (Last Will) |
| `aquafeeder/status` | aparelho → você | JSON retido, a cada 60 s e a cada evento |
| `aquafeeder/evento` | aparelho → você | uma mensagem por alimentação |

**O que o MQTT dá e o Telegram não dá:** alarme automático de "parou de
funcionar". Se o alimentador travar, cair a luz ou cair a internet, é o próprio
broker que publica `online = 0`. Com Telegram você recebe silêncio — que é
indistinguível de "está tudo bem e ninguém mandou mensagem".

```bash
mosquitto_pub -h SEU-BROKER -p 8883 -u user -P senha -t aquafeeder/cmd -m "feed 2"
mosquitto_sub -h SEU-BROKER -p 8883 -u user -P senha -t 'aquafeeder/#' -v
```

As travas de segurança valem igual: limite diário, máximo por acionamento e
intervalo mínimo. Comando barrado responde em `aquafeeder/evento` com
`{"erro":"..."}`.

## Opção 3 — VPN / Tailscale (acesso à interface completa)

Se quer o vídeo ao vivo e a interface inteira de fora de casa, instale
**Tailscale** (ou WireGuard) num computador/Raspberry que fique ligado em casa e
entre na rede por VPN. Aí você acessa `http://aquafeeder.local` como se
estivesse em casa.

Muitos roteadores modernos já trazem servidor VPN embutido — vale checar.

## Opção 4 — não faça isso: porta aberta no roteador

Encaminhar a porta 80 do alimentador para a internet expõe um dispositivo
caseiro a varredura constante. Se ainda assim quiser:

- **defina uma senha forte na interface** (sem senha, qualquer um alimenta seus peixes);
- use uma porta externa alta e aleatória;
- nunca exponha a porta 81 (vídeo);
- prefira colocar atrás de um proxy reverso com HTTPS.

## Integrando com outras coisas

A [API HTTP](04-firmware.md#api-http) é aberta dentro da rede. Exemplos de uso:

- **n8n / Home Assistant** — chamada HTTP em `/api/feed?p=1` em qualquer fluxo.
- **Alexa/Google** via rotina do Home Assistant.
- **Script no PC**: `curl -b ck.txt -X POST http://aquafeeder.local/api/feed?p=1`

Um detalhe útil: o `/api/status` devolve `fedToday`, então você pode montar um
alerta externo ("se às 21h ainda não alimentou hoje, me avise").

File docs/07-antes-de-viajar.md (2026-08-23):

# 7. Antes de viajar

Alimentador automático é o tipo de coisa que só falha quando você não está lá.
Este checklist existe para isso.

## Duas semanas antes

- [ ] Deixe o alimentador **rodando de verdade** por 7 dias, com você em casa.
      É o único teste que vale. Confira no *Histórico* se todos os horários
      dispararam.
- [ ] Veja se sobra ração no fundo do aquário depois das refeições. Se sobra,
      **diminua** os passos por porção.
- [ ] Cheque se o motor está esquentando muito. Morno é normal; quente demais
      significa passo rápido demais — aumente os µs por passo.

## Uma semana antes

- [ ] Troque a ração do funil por ração nova e seca.
- [ ] Sachê de sílica gel novo.
- [ ] Desmonte a calha e limpe (é só puxar). Pó de ração acumula ali.
- [ ] Verifique se a rosca gira livre: *Manutenção → Avançar*.
- [ ] Confirme o `Máx. porções/dia` — deixe justo, não generoso.
- [ ] Faça um teste de queda de energia: **desligue a fonte no meio de um
      horário programado e ligue 10 minutos depois.** Tem que alimentar ao voltar.

## Um dia antes

- [ ] Bot do Telegram respondendo `/status` e `/foto` do **4G do celular**
      (não do Wi-Fi de casa — precisa ser um teste real de acesso externo).
- [ ] Bateria/nobreak do roteador, se tiver.
- [ ] Reserve o IP do alimentador no roteador (DHCP estático), para não perder
      o acesso se o roteador reiniciar.
- [ ] Anote o IP e a senha da interface em algum lugar acessível na viagem.
- [ ] Câmera enquadrando a superfície da água e a saída da calha — assim você
      vê tanto os peixes quanto se a ração está caindo.
- [ ] Encha o funil só com o necessário para o período + 1 semana.

## Plano B (importante)

Nenhum equipamento caseiro tem 100% de confiabilidade. Combine com uma
segunda camada:

1. **Uma pessoa de confiança com a chave** — e avise que existe um alimentador
   automático, para ela não alimentar em dobro. Deixe ração porcionada em
   saquinhos, um por dia, e peça para usar **só se você pedir**.
2. **Jejum é seguro.** Peixe tropical adulto saudável passa tranquilamente
   5–7 dias sem comer. Se a viagem é de até uma semana, o risco de morrer de
   fome é muito menor que o de morrer por excesso de comida ou por pico de
   amônia. Configure com parcimônia.
3. Se a viagem for longa (>3 semanas), a manutenção da água é um problema
   maior que a comida: troca parcial de água é insubstituível.

## O que monitorar durante a viagem

- Uma foto por dia (`/foto`) já mostra muito: água turva, ração acumulada no
  fundo, peixe boiando, nível do funil.
- Se ligar *Avisar a cada alimentação*, a ausência de mensagem no horário é
  o sinal de alarme: pode ser Wi-Fi, energia ou entupimento.
- Com sensor de grãos ligado, você recebe aviso explícito de "não caiu ração".

## Se der problema e você estiver longe

| Sintoma | Provável causa | O que fazer à distância |
|---|---|---|
| Não responde nada | Falta de energia ou Wi-Fi | Peça para alguém reiniciar a fonte e o roteador |
| Responde mas "não caiu ração" | Rosca entupida / ração empedrada | Mande `/alimentar` algumas vezes; se tiver acesso à interface, use Recuar/Avançar |
| Alimentou mas o peixe não come | Ração no lugar errado ou peixe doente | Foto + pedir ajuda presencial |
| Alimentou demais | Limite alto demais | Baixe `Máx. porções/dia` para 1 e peça sifonagem |

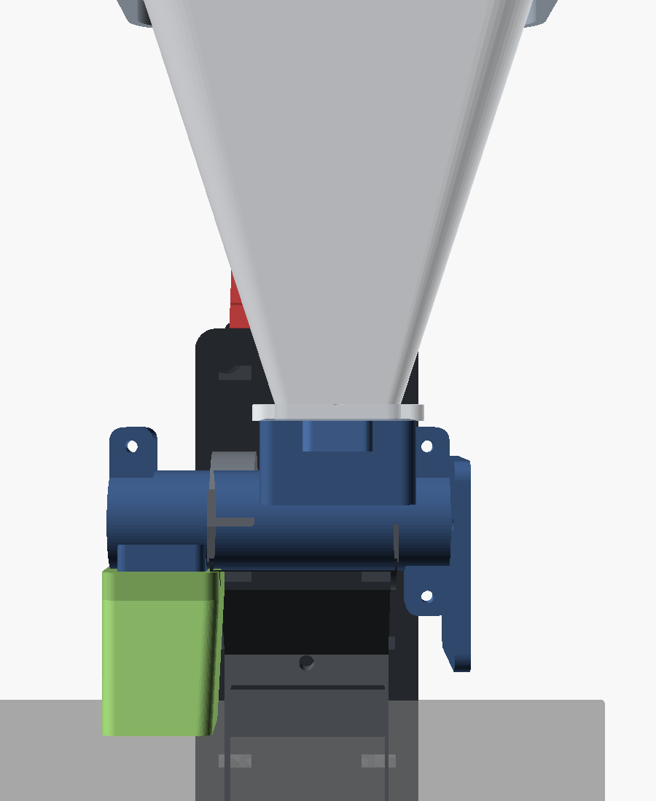
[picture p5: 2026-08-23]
docs/img/vista_frente.png

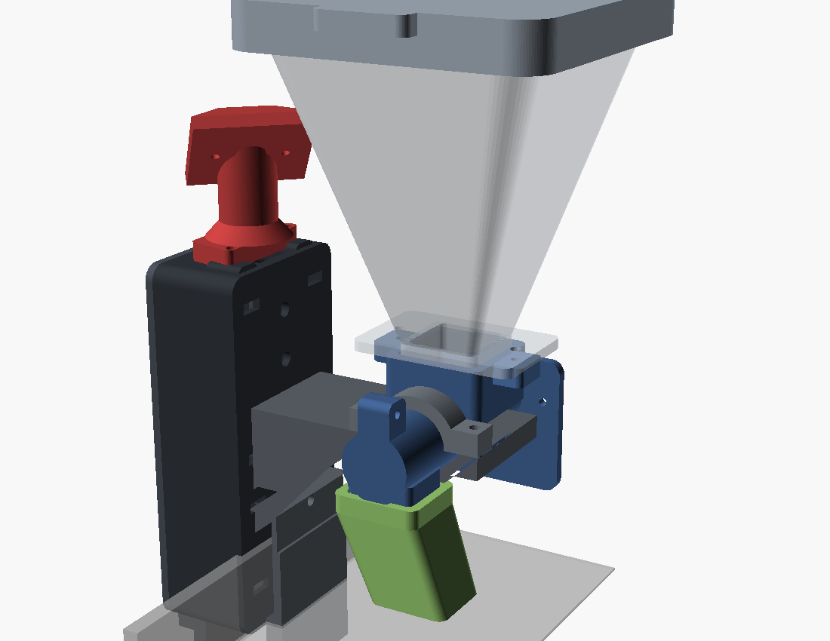
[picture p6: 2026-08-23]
docs/img/vista_camera.png

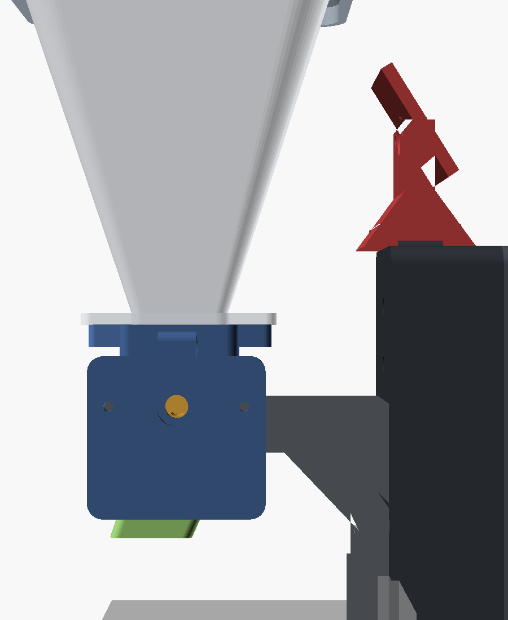
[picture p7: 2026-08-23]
docs/img/vista_lado.png

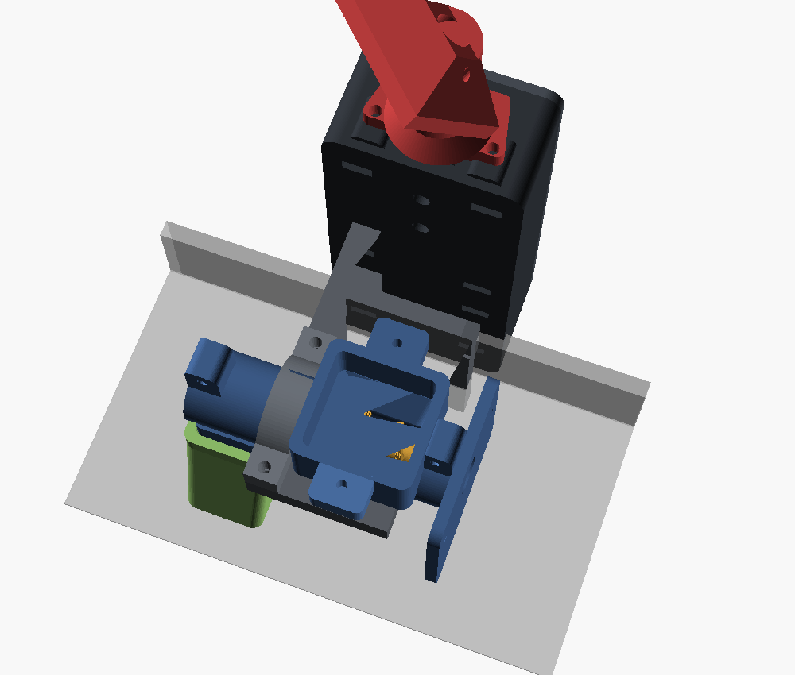
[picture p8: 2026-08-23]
docs/img/vista_cima.png

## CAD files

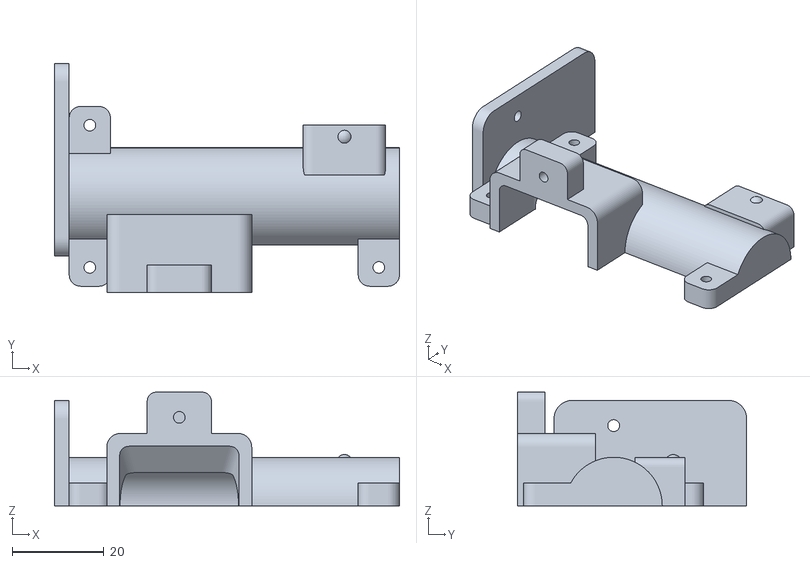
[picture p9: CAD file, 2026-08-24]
stl/motor_28byj/tubo_metade_a.stl
75.2 x 50.0 x 24.8

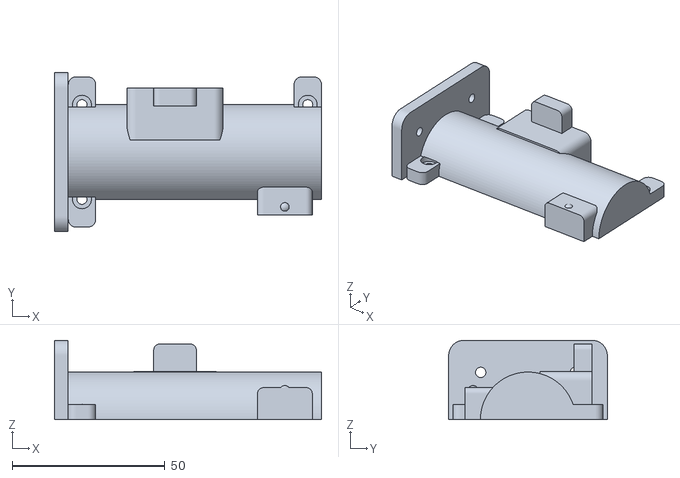
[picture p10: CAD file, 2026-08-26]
stl/motor_nema17/tubo_metade_b.stl
87.5 x 52.0 x 26.0

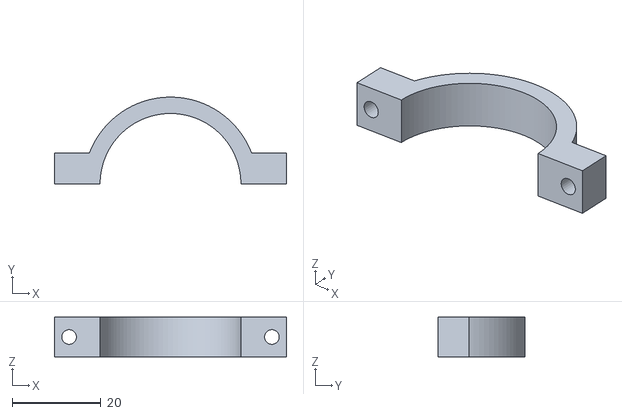
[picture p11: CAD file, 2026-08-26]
stl/tampa_do_berco.stl
52.4 x 19.6 x 9.00

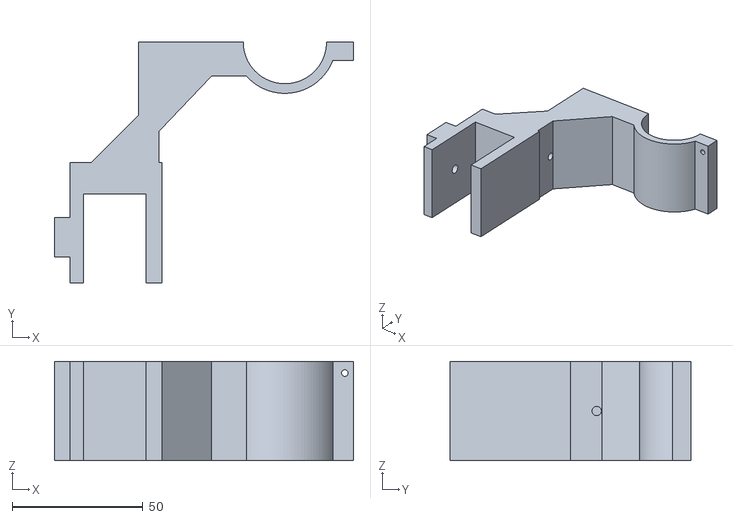
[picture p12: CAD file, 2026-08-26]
stl/bracadeira.stl
114.2 x 92.0 x 38.0

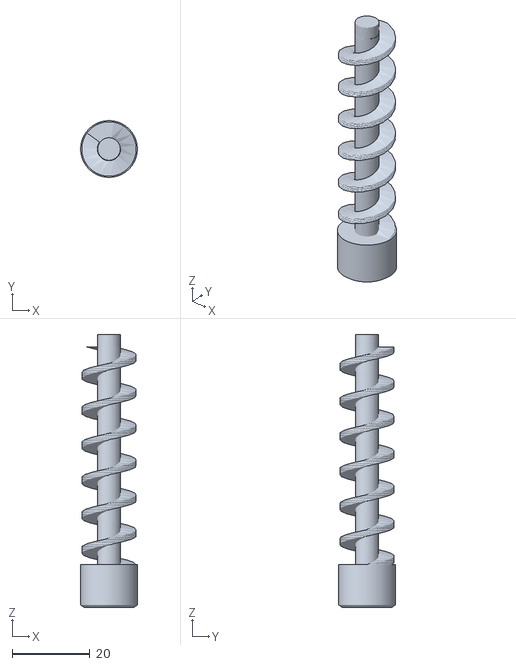
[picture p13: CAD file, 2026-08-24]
stl/motor_28byj/rosca.stl
14.6 x 14.6 x 70.2

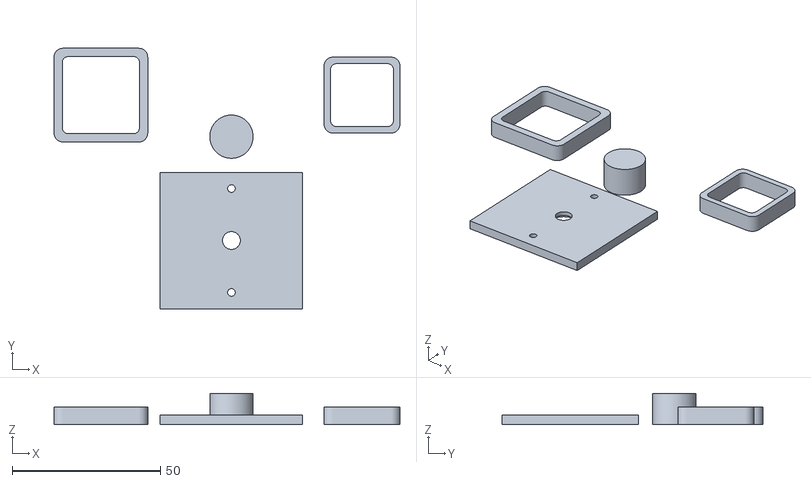
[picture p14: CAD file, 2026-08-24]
stl/motor_28byj/peca_de_teste.stl
116.6 x 87.8 x 10.5

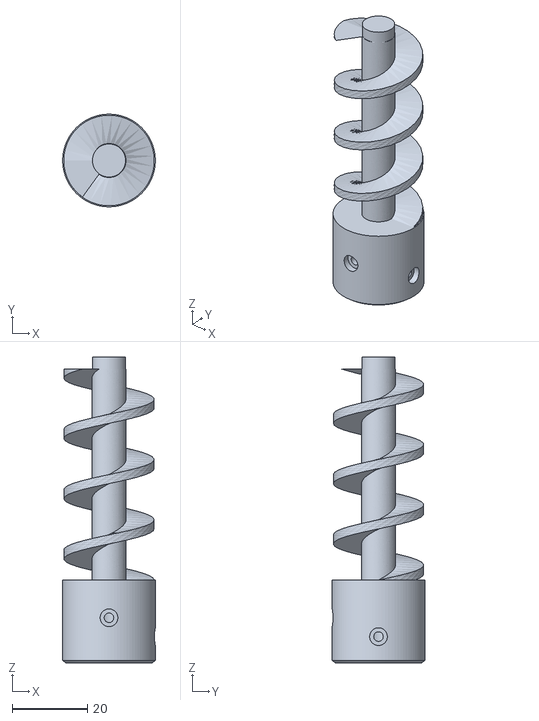
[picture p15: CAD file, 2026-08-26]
stl/motor_nema17/rosca.stl
24.6 x 24.6 x 81.2

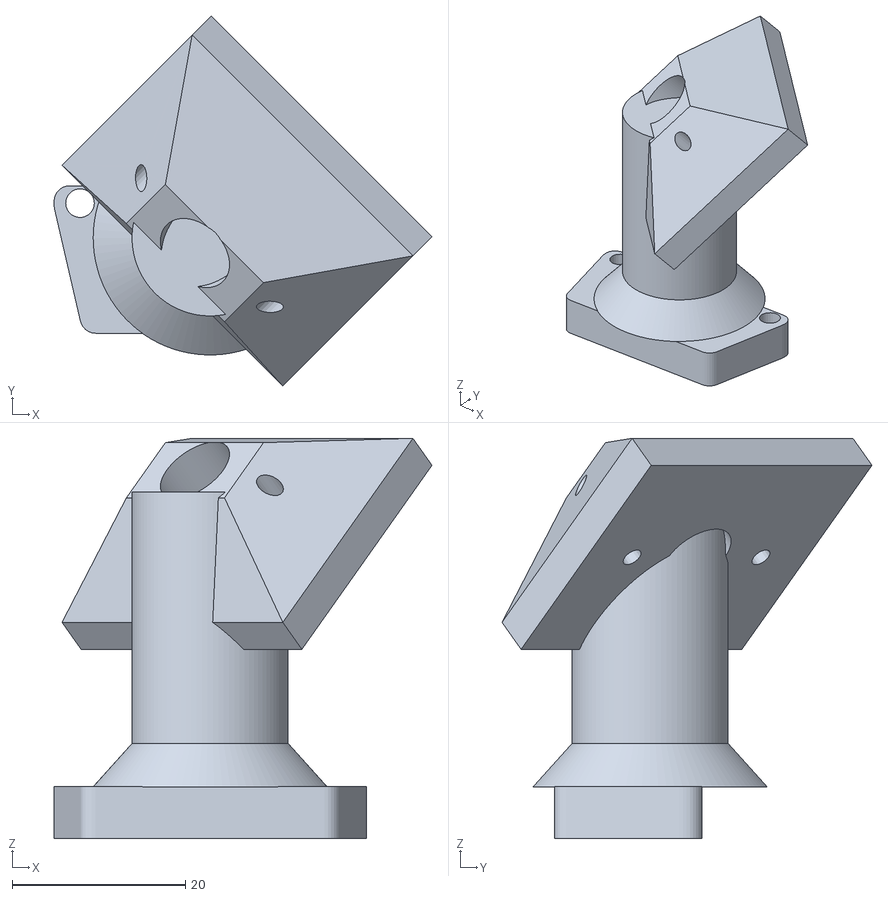
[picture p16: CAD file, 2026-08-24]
stl/suporte_da_camera.stl
43.6 x 42.7 x 46.2

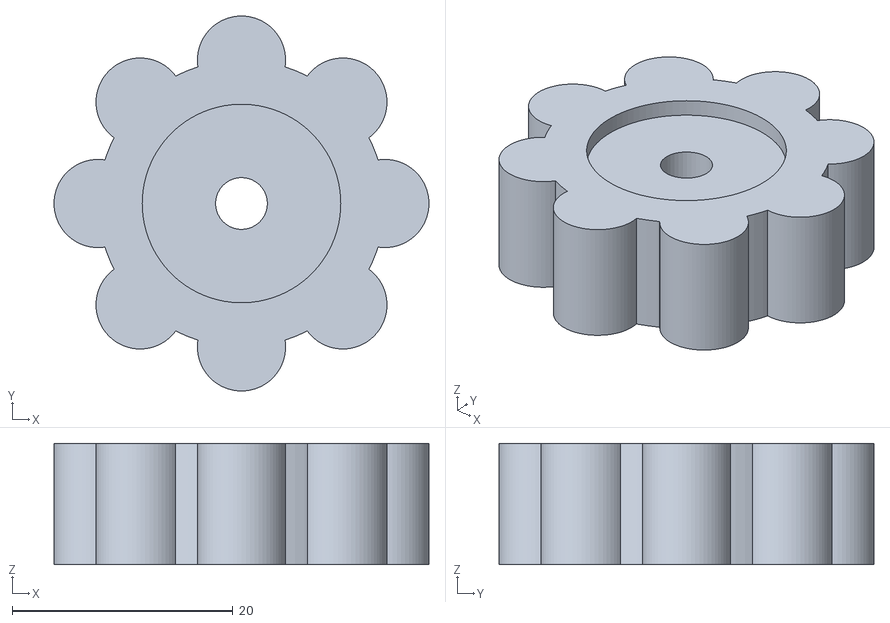
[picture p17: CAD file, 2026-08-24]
stl/manipulo.stl
34.0 x 34.0 x 11.0

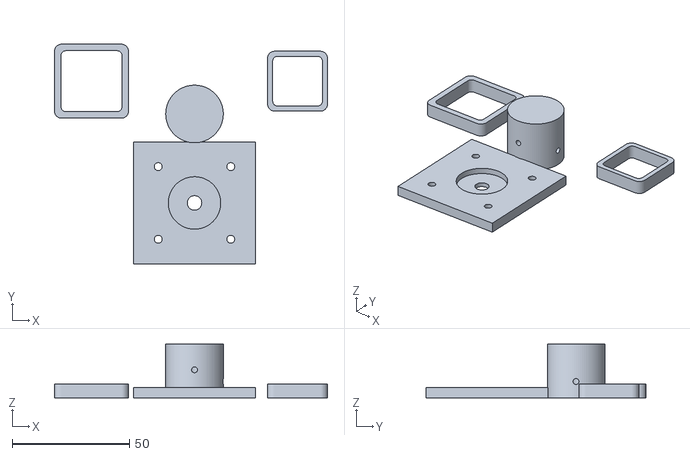
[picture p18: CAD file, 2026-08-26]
stl/motor_nema17/peca_de_teste.stl
116.6 x 93.8 x 23.0

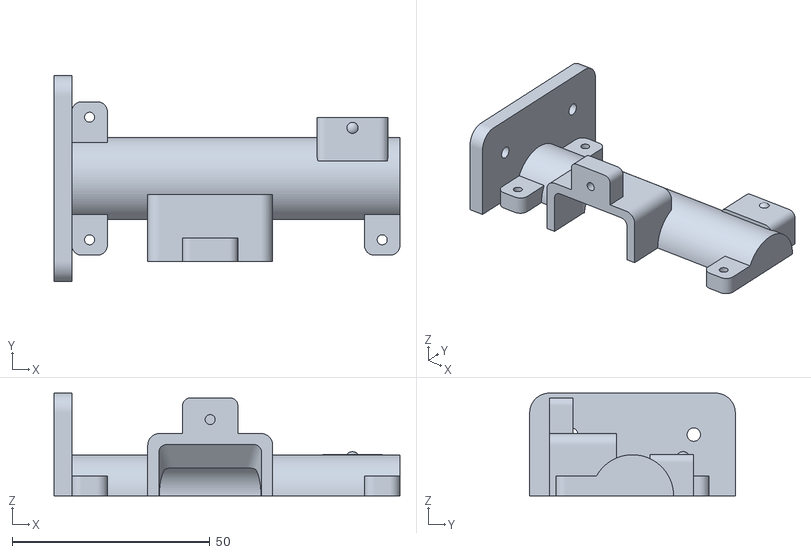
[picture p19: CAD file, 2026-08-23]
stl/motor_nema17/barrel_a.stl
87.5 x 52.0 x 26.0

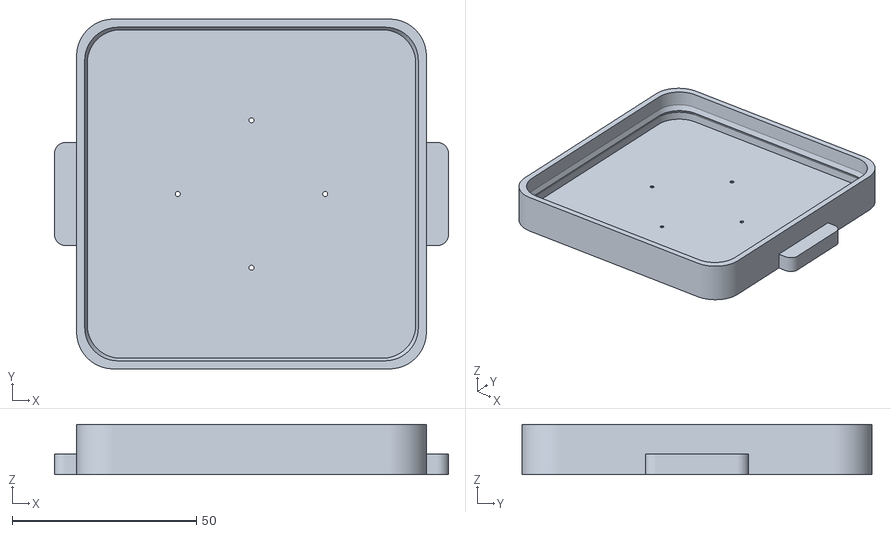
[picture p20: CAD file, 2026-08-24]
stl/tampa_do_funil.stl
106.9 x 94.9 x 13.6

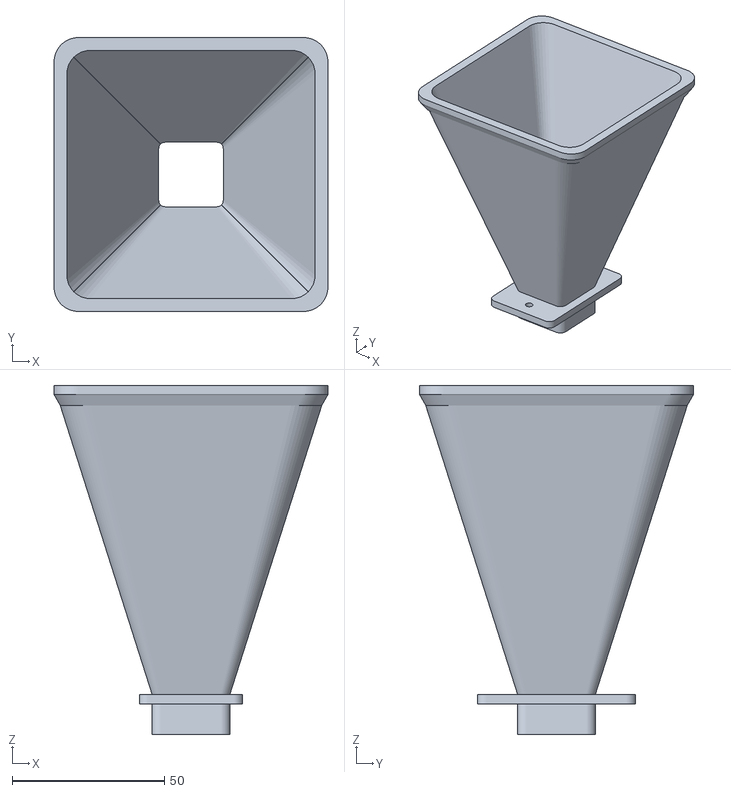
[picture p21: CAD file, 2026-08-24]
stl/funil.stl
90.0 x 90.0 x 114.7

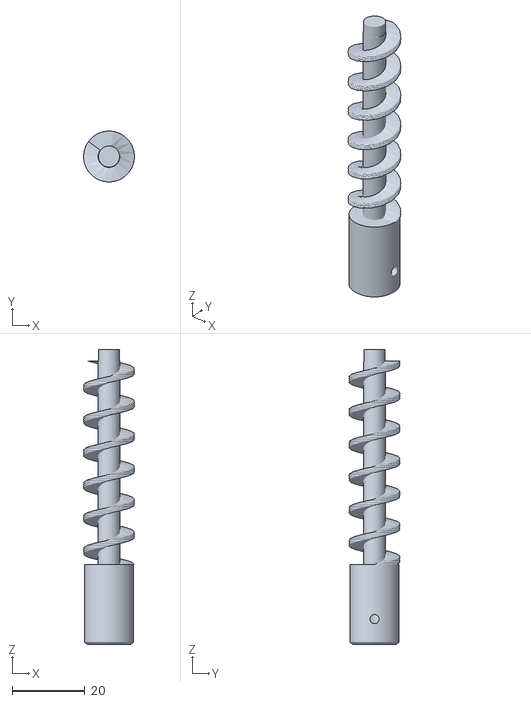
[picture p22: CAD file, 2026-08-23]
stl/motor_nema17/auger.stl
14.0 x 14.0 x 81.2

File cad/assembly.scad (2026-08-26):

// =====================================================================
//  AquaFeeder -- vista de conjunto (NAO imprimir, e so para conferir)
//
//  Referencia da montagem: eixo do tubo = eixo X, na altura z = 0.
//  z = -46 e o topo da borda do aquario.
//
//  openscad -o ../docs/img/montagem.png --imgsize=1600,1200 \
//           --camera=0,0,0,62,0,28,520 assembly.scad
// =====================================================================
include <common.scad>
use <barrel.scad>
use <auger.scad>
use <hopper.scad>
use <lid.scad>
use <chute.scad>
use <bracket.scad>
use <saddle_cap.scad>
use <box_base.scad>
use <box_lid.scad>
use <cam_pod.scad>

SHOW_HOPPER = true;
SHOW_BOX    = true;
SHOW_TANK   = true;
CUTAWAY     = false;   // true = corta tudo em y>0 para ver o miolo
EXPLODE     = 0;       // 0 = montado, 1 = vista explodida

bracket_x = 11;        // inicio do berco ao longo do tubo
bracket_w = 38;
cap_x     = 40;        // tampa do berco (janela livre entre colar e calha)
mast_h_a  = 46;        // igual ao mast_h de bracket.scad
tube_y_a  = 52;        // igual ao tube_y de bracket.scad
mast_cx   = bracket_x + bracket_w/2;

module aquafeeder() {
    e = EXPLODE;
    // ---- mecanismo -------------------------------------------------
    color("#4a6fa5") translate([0,  e*26, 0]) barrel_half("A");
    color("#3d5c8a") translate([0, -e*26, 0]) barrel_half("B");
    color("#d8a13a") translate([0.6 - e*46, 0, 0]) rotate([0, 90, 0]) auger();
    color("#8fbf6a") translate([outlet_x0 + outlet_len/2, 0, -barrel_od/2 - 30.8 - e*34]) chute();

    // ---- funil -----------------------------------------------------
    if (SHOW_HOPPER) {
        color("#cfd6dd", 0.55) translate([collar_cx, 0, lug_top + e*44]) hopper();
        color("#9aa5b1") translate([collar_cx, 0, lug_top + 101.2 + 2.6 + e*66])
            rotate([180, 0, 0]) lid();
    }

    // ---- estrutura -------------------------------------------------
    color("#5a5f66") translate([bracket_x, -tube_y_a, -mast_h_a])
        rotate([90, 0, 90]) bracket();
    color("#6e747c") translate([cap_x, 0, EXPLODE*30]) rotate([90, 0, 90]) saddle_cap();

    // ---- eletronica ------------------------------------------------
    if (SHOW_BOX) {
        translate([mast_cx, -56, -16.4]) rotate([0, 90, 0]) rotate([90, 0, 0]) {
            color("#2e3238") box_base();
            color("#454b53") translate([0, 0, box_iz + box_wall + 2.6])
                rotate([180, 0, 0]) box_lid();
        }
        // pe do pod assenta nas 2 bossas do topo da caixa (x = mast_cx +-15)
        color("#b23a3a") translate([mast_cx, -64.4, 42]) cam_pod();
    }

    // ---- contexto: vidro do aquario e linha d'agua ------------------
    // borda do aquario: y de -77 a -53. Agua: y > -53, topo em z = -72.
    if (SHOW_TANK) {
        %translate([-40, -58, -130]) cube([150, 5, 84]);       // vidro
        %translate([-40, -53, -72]) cube([150, 80, 1]);        // superficie da agua
    }
}

if (CUTAWAY)
    difference() { aquafeeder(); translate([-100, 0, -200]) cube([400, 200, 400]); }
else
    aquafeeder();

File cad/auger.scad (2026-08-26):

// =====================================================================
//  AquaFeeder -- rosca sem-fim (auger)
//  Imprimir EM PE (como esta), cubo para baixo. Sem suporte.
//  0.2 mm de camada / 3 paredes / 30% preenchimento / PETG
// =====================================================================
include <common.scad>

// helice: um setor de coroa circular extrudado com twist gera o helicoide.
// angulo do setor = 360 * espessura_da_aleta / passo
module auger_flight(len) {
    ang   = 360 * flight_t / auger_pitch;
    twist = -360 * len / auger_pitch;
    // slices menor = render mais rapido; 0.6mm por fatia ja fica liso
    linear_extrude(height = len, twist = twist, slices = ceil(len / 0.6), convexity = 8, $fn = 40)
        union() {
            circle(d = auger_core);
            intersection() {
                difference() {
                    circle(d = auger_od);
                    circle(d = auger_core - 3);   // encrava a aleta ~1.5mm no nucleo (mais forte)
                }
                pie(auger_od, ang);
            }
        }
}

// furo do parafuso de fixacao do eixo + rebaixo p/ a cabeca na boca externa.
// Desenhado ao longo de +Z: a boca fica na superficie do cubo (raio hub_d/2).
module shaft_screw() {
    cylinder(d = m3_tap, h = hub_d);                          // furo rosqueado
    translate([0, 0, hub_d/2 - n17_screw_head_h])
        cylinder(d = n17_screw_head_d, h = hub_d);            // rebaixo da cabeca
}

module auger() {
    total = hub_len + auger_len + stub_len;
    difference() {
        union() {
            cylinder(d = hub_d, h = hub_len);                          // mancal dianteiro
            cylinder(d = auger_core, h = hub_len + auger_len);         // nucleo
            translate([0, 0, hub_len]) auger_flight(auger_len);        // helice
            translate([0, 0, hub_len + auger_len])                     // mancal traseiro
                cylinder(d = stub_d, h = stub_len);
        }
        // encaixe do eixo do motor
        if (motor_type == "NEMA17") {
            // Encaixe em "D": acompanha o achatado do eixo com folga de deslize
            // (ver n17_socket_c). A face plana pega o torque -- assim a rosca
            // encaixa firme e nao depende do parafuso para nao patinar.
            translate([0, 0, -eps])
                n17_dsocket(n17_socket_d + eps, n17_socket_c + fit/2);
            // DOIS parafusos M3 radiais a 90 graus: o em X cai sobre o achatado
            // (trava axial + reforca o aperto); o em Y e opcional. O torque quem
            // segura e o achatado do encaixe, nao os parafusos.
            translate([0, 0, 7])  rotate([0, 90, 0]) shaft_screw();
            translate([0, 0, 12]) rotate([90, 0, 0]) shaft_screw();
        } else {
            translate([0, 0, -eps]) dshaft(socket_depth + eps, 0.15 + fit/2);
        }

        // chanfro na base (evita pe de elefante travando no tubo)
        difference() {
            translate([0, 0, -eps]) cylinder(d = hub_d + 4, h = 0.9);
            cylinder(d1 = hub_d - 1.8, d2 = hub_d + 0.9, h = 1.0);
        }
    }
    // marca visual do sentido de giro (nao funcional)
}

auger();

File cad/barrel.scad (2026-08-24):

// =====================================================================
//  AquaFeeder -- tubo transportador, partido ao meio no plano y=0
//
//  openscad -o barrel_a.stl -D 'PART="A"' barrel.scad
//  openscad -o barrel_b.stl -D 'PART="B"' barrel.scad
//
//  A = metade com roscas M3 (furo 2.55)   B = metade com furos passantes
//  Imprimir com a face plana na mesa (a orientacao ja sai pronta). SEM SUPORTE.
//  4 paredes / 25% / PETG.
// =====================================================================
include <common.scad>

PART  = "A";
PRINT = true;

ear_z0   = 5;
ear_z1   = barrel_od/2 + ear_out;
ear_screw_z = 15.5;
outlet_cx   = outlet_x0 + outlet_len/2;
boss_z0     = -barrel_od/2 - boss_h;

// posicao das orelhas: [x0, lado]  (+1 = topo, -1 = fundo)
ears = [[0, 1], [0, -1], [barrel_len - ear_w, 1]];

// ---------------------------------------------------------------------
module ear(x0, s) {
    rotate([90, 0, 0])
        linear_extrude(height = 2*ear_t, center = true)
            translate([x0 + ear_w/2, s * (ear_z0 + ear_z1)/2])
                rrect(ear_w, ear_z1 - ear_z0, 2.5);
}

module ear_screw(x0, s, part) {
    translate([x0 + ear_w/2, 0, s * ear_screw_z]) rotate([-90, 0, 0]) {
        if (part == "A") {
            translate([0, 0, -0.2]) cylinder(d = m3_tap, h = ear_t + 0.4);
        } else {
            translate([0, 0, -ear_t - 0.2]) cylinder(d = m3_free + fit, h = ear_t + 0.4);
            translate([0, 0, -ear_t - 0.2]) cylinder(d = m3_head, h = m3_head_h + 0.2);
        }
    }
}

// ---------------------------------------------------------------------
// Fixacao do motor -- muda conforme motor_type (ver common.scad)
module motor_plate() {
    if (motor_type == "NEMA17") {
        translate([-n17_plate_t, 0, 0]) rotate([0, 90, 0])
            linear_extrude(n17_plate_t) rrect(n17_plate, n17_plate, 5);
    } else {
        translate([-plate_t, 0, plate_dz]) rotate([0, 90, 0])
            linear_extrude(plate_t) rrect(plate_h, plate_w, 4);
    }
}

module motor_cuts() {
    if (motor_type == "NEMA17") {
        xcyl(n17_shaft_d + 1.2, -n17_plate_t - 1, 1.0);                    // eixo
        xcyl(n17_boss_d + fit, -n17_plate_t - eps, -n17_plate_t + n17_boss_h);
        // 4 furos M3: o parafuso entra por dentro e rosca no proprio motor
        for (sy = [-1, 1], sz = [-1, 1])
            translate([-n17_plate_t - 1, sy * n17_hole_p/2, sz * n17_hole_p/2])
                rotate([0, 90, 0]) cylinder(d = n17_hole_d + fit, h = n17_plate_t + 2);
    } else {
        xcyl(m_shaft_d + 1.0, -plate_t - 1, 1.0);
        xcyl(m_boss_d + 0.6, -plate_t - eps, -plate_t + m_boss_h);
        for (s = [-1, 1])
            translate([-plate_t - 1, s * m_hole_pitch/2, 0])
                rotate([0, 90, 0]) cylinder(d = m_hole_d + fit, h = plate_t + 2);
    }
}

module collar() {
    // colar (socket do funil)
    translate([collar_cx, 0, collar_z0])
        linear_extrude(collar_z1 - collar_z0)
            rrect(socket_sq + 2*collar_wall, socket_sq + 2*collar_wall, 3);
    // orelhas laterais que recebem o flange do funil. Nascem da parede
    // externa do colar (y = 13..15.8), por isso a primeira camada da orelha
    // ja tem material embaixo na impressao.
    for (s = [-1, 1])
        translate([collar_cx, s * lug_y, lug_top - lug_t])
            rbox(14, 11, lug_t, 2);
}

module outlet_boss() {
    translate([outlet_cx, 0, boss_z0])
        linear_extrude(boss_h + 6) rrect(boss_x, boss_y, 2);
    // meias-esferas de retencao da calha (uma em cada metade)
    for (s = [-1, 1])
        translate([outlet_cx, s * (boss_y/2 - 1.1), boss_z0 + 2.6]) sphere(r = 1.8);
}

// ---------------------------------------------------------------------
module barrel_solid() {
    union() {
        xcyl(barrel_od, 0, barrel_len);
        motor_plate();
        collar();
        outlet_boss();
        for (e = ears) ear(e[0], e[1]);
    }
}

module barrel_cuts(part) {
    // furo interno + bolsa do mancal traseiro
    xcyl(bore_d + fit, 0, bore_end);
    xcyl(stub_d + 0.8 + fit, bore_end, bore_end + stub_len + 0.4);

    // eixo, ressalto e furos do motor escolhido
    motor_cuts();

    // socket do funil + funil de transicao ate a janela de entrada
    translate([collar_cx, 0, 8])
        linear_extrude(collar_z1 - 8 + 1)
            rrect(socket_sq + fit, socket_sq + fit, 2);
    hull() {
        translate([collar_cx, 0, 8 - 0.1])
            linear_extrude(0.1) rrect(socket_sq + fit, socket_sq + fit, 2);
        translate([collar_cx, 0, 1.5])
            linear_extrude(0.1) rrect(inlet_len, inlet_w, 2);
    }

    // saida (fundo)
    translate([outlet_cx, 0, -12])
        cube([outlet_len, outlet_w, 14], center = true);

    // roscas M3 das orelhas do colar (flange do funil entra por cima)
    for (s = [-1, 1])
        translate([collar_cx, s * lug_y, lug_top + 0.2])
            rotate([180, 0, 0]) cylinder(d = m3_tap, h = lug_t - 0.6);

    // parafusos que unem as metades
    for (e = ears) ear_screw(e[0], e[1], part);
}

module half_space(a) {
    translate([-80, a ? 0 : -200, -120]) cube([320, 200, 240]);
}

module barrel_half(part) {
    difference() {
        intersection() {
            barrel_solid();
            half_space(part == "A");
        }
        barrel_cuts(part);
    }
}

// ---------------------------------------------------------------------
if (PRINT)
    rotate([(PART == "A") ? 90 : -90, 0, 0]) barrel_half(PART);
else
    barrel_half(PART);

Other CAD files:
stl/motor_nema17/tubo_metade_a.stl
stl/motor_28byj/tubo_metade_b.stl
stl/motor_28byj/barrel_b.stl
stl/motor_28byj/test_fit.stl
cad/box_base.scad
cad/box_lid.scad
cad/bracket.scad
cad/cam_pod.scad
cad/check_interferencia.scad
cad/chute.scad
cad/common.scad
cad/hopper.scad
cad/knob.scad
cad/lid.scad
cad/saddle_cap.scad
cad/test_fit.scad
stl/box_base.stl
stl/box_lid.stl
stl/bracket.stl
stl/caixa_eletronica.stl
stl/calha.stl
stl/calha_com_sensor.stl
stl/cam_pod.stl
stl/chute.stl
stl/knob.stl
stl/lid.stl
stl/montagem_completa.stl
stl/montagem_explodida.stl
stl/motor_28byj/auger.stl
stl/motor_nema17/test_fit.stl
stl/tampa_da_caixa.stl

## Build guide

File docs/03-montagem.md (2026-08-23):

# 3. Montagem

Vista explodida

Como fica por dentro (corte no meio do tubo):

Corte

## Parafusos usados

| Onde | Parafuso | Qtd |
|---|---|---|
| Metades do tubo (orelhas) | M3 × 8 | 3 |
| Motor no prato — 28BYJ-48 | M3 × 10 | 2 |
| Motor no prato — NEMA 17 | M3 × 10 | 4 |
| Funil no colar do tubo | M3 × 12 | 2 |
| Tampa do berço na braçadeira | M3 × 16 | 2 |
| Tampa da caixa | M3 × 10 | 4 |
| Caixa no mastro | M4 × 12 | 2 |
| Suporte da câmera na caixa | M3 × 12 | 2 |
| PCB da câmera no suporte | M2 × 6 | 2 |
| Aperto da braçadeira | M4 × 30 + porca M4 | 1 |

Total: **11 × M3 curtos, 2 × M3 × 16, 2 × M4 × 12, 2 × M2 × 6, 1 × M4 × 30 + porca**.
Um kit variado de M3 de bicicleta/eletrônica resolve.

Tudo que rosca no plástico rosca **direto** (sem inserto): entre devagar, sem
apertar até o fim da força.

## Passo 1 — rosca no tubo

1. Limpe a rebarba da hélice da rosca (`auger`) com um estilete.
2. Encaixe o eixo do motor no cubo da rosca:
   - **28BYJ-48:** o eixo é achatado dos dois lados e entra com pressão firme dos
     dedos. Duro? Lima fina. Frouxo? Uma gota de cola instantânea.
   - **NEMA 17:** o cubo é fundo o bastante para engolir 20–25 mm de eixo, sem
     precisar cortar nada. O eixo desliza com folga de 0,35 mm — é de propósito:
     furo vertical em FDM sai menor que o nominal, e quem centra a rosca são os
     mancais dela (o cubo e a ponta), não o eixo. Quem tira a folga e pega o
     torque são os **dois parafusos M3 radiais** (a 90° um do outro): gire a rosca
     até um deles cair em cima do **achatado do eixo** e aperte. Se o seu eixo for
     redondo liso, lime um chanfro onde o parafuso encosta.
3. Deite a rosca na metade **B** do tubo, com a ponta fina (mancal traseiro) no
   fundo da bolsa e o cubo do lado do prato do motor.
4. Feche com a metade **A** e aperte os **3 M3 × 8** nas orelhas
   (2 na frente, 1 atrás). A cabeça entra pelo lado B.
5. **Teste antes de continuar:** gire o eixo do motor com a mão. A rosca tem que
   girar livre, com o mínimo de arrasto. Se travar, afrouxe os parafusos, alinhe
   e aperte de novo — ou lime a hélice.

## Passo 2 — motor

**28BYJ-48:** parafuse no prato com **2 M3 × 10** (roscam direto no plástico, entre
devagar), com o corpo do motor **para baixo**. O ressalto do eixo entra no rebaixo
do prato — é isso que garante o alinhamento.

**NEMA 17:** parafuse com **4 M3 × 10** no quadrado de 31 mm. Os parafusos entram
pelo lado de dentro (entre o prato e o tubo) e roscam na carcaça do próprio motor,
então use chave allen com ponta esférica. O ressalto de 22 mm do motor entra no
rebaixo do prato.

## Passo 3 — funil

1. Encaixe o spigot (a saia quadrada) do funil no socket do tubo.
2. Parafuse os **2 M3 × 12** do flange nas orelhas do colar. Esses dois
   parafusos também prendem as duas metades do tubo na região do colar.
3. Jogue um sachê de sílica gel dentro do funil antes de pôr ração.

## Passo 4 — calha

Encaixe a calha (`chute`) empurrando por baixo no boss do tubo até as duas
covinhas estalarem nas meias-esferas. Ela sai com um puxão firme, para limpeza.
A boca inclinada da calha aponta **para dentro do aquário**.

## Passo 5 — braçadeira

1. Encaixe a porca M4 no alojamento sextavado da garra externa (se ficar
   folgada, uma gota de cola).
2. Rosqueie o M4 × 30 e encaixe o manípulo na cabeça.
3. Apoie a braçadeira na borda do aquário, deite o tubo no berço e feche com a
   tampa do berço + **2 M3 × 16**. Onde o berço abraça o tubo depende do motor
   (é a mesma peça, só muda a posição):
   - **28BYJ-48:** berço em x = 11 a 49 mm, tampa em x = 40 a 49 mm
   - **NEMA 17:** berço em x = 24 a 62 mm, tampa em x = 53 a 62 mm
4. Aperte o manípulo até firmar na borda. **Não precisa de força de macaco** —
   plástico racha.

Confira: a saída da calha tem que ficar **acima da linha d'água**, uns 2 a 5 cm.
Se no seu aquário a água está muito alta ou muito baixa, ajuste `mast_h` em
`cad/bracket.scad` e reimprima a braçadeira (é a única peça afetada).

> **Aquário com tampa?** Fica mais firme apoiar o conjunto na tampa e fazer um
> furo de ~25 mm para a calha passar. Nesse caso você não precisa da braçadeira
> nem da tampa do berço.

## Passo 6 — eletrônica e câmera

1. Fixe as placas na caixa (pinos, abraçadeira ou dupla face).
2. Faça as ligações da [seção 2](02-eletronica.md), com o capacitor junto do ULN2003.
3. Parafuse a caixa no mastro (2 × M4 × 12, roscam no plástico), com a ponta do USB **para cima**.
4. Monte a PCB da câmera no `cam_pod` com 2 M2 × 6 e parafuse o pod em cima da caixa.
5. Passe o cabo flat da câmera com cuidado — ele é frágil e o conector tem
   trava (levante a aba escura, insira, abaixe a aba).
6. Cabos do motor e da fonte saem pela **parte de baixo** da caixa, em laço.

O suporte da câmera tem **duas** inclinações embutidas: `cam_tilt` (45° para
baixo) e `cam_yaw` (45° na horizontal). O *yaw* existe porque olhando reto a
câmera ficaria de cara com a parede do funil — girada 45° ela passa ao lado e
enquadra a superfície da água e a saída da calha:

O que a câmera vê

Se a imagem sair de cabeça para baixo ou espelhada, corrija em
*Ajustes → Câmera* (girar/espelhar) — não precisa reimprimir. Se quiser mudar
para onde ela aponta, mexa em `cam_tilt` / `cam_yaw` em `cad/cam_pod.scad` e
reimprima (15 g). O pod é simétrico: montando virado 180° na caixa, ele olha
para o outro lado do aquário.

## Passo 7 — primeiro teste, ainda sem ração

Ligue, configure o Wi-Fi ([seção 4](04-firmware.md)) e use
*Agora → Manutenção da rosca → Avançar*. A rosca deve girar suave, sem barulho
de trava e sem esquentar o motor além de "morno".

Só depois ponha ração e vá para a [calibração](05-calibracao.md).

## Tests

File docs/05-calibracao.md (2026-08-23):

# 5. Calibração da dose

O firmware não sabe o que é "uma porção" para o *seu* peixe. Isso se resolve em
10 minutos e é o passo que mais influencia o resultado final.

## Quanto o peixe come, de verdade

Regra prática: a quantidade que os peixes limpam em **2 a 3 minutos**, sem
sobrar nada no fundo. Para a maioria dos aquários domésticos (10 a 60 L,
peixes pequenos) isso dá algo entre **0,2 e 0,6 ml por refeição** — bem menos
do que a intuição sugere.

Alimente **menos** que o normal por vez e use dois horários em vez de um só.
Ração que sobra vira amônia, e amônia mata.

## Passo a passo

1. Ponha ração no funil (pelo menos 1/3, para o peso ajudar a descer).
2. Encha a rosca: *Agora → Manutenção → Avançar* umas 3 vezes, até começar a
   cair ração de forma regular. Recolha essa ração num potinho, não jogue no aquário.
3. Ponha um papel/potinho embaixo da calha.
4. Clique em **1 porção** e olhe quanto caiu.
5. Ajuste em *Ajustes → Dosagem → Passos por porção*:

| Objetivo | Passos por porção | Dose aproximada |
|---|---|---|
| bem pouco | 512 | ~0,12 ml |
| **padrão** | **1024** | **~0,23 ml** |
| médio | 2048 (meia volta) | ~0,46 ml |
| bastante | 4096 (uma volta) | ~0,93 ml |

6. Repita 5 vezes seguidas e veja se a dose é **repetível**. Variação de ±20% é
   normal com ração granulada; mais que isso indica ração muito grande para a
   rosca ou hélice com rebarba.

## Depois de calibrar, ajuste as travas

Em *Ajustes → Segurança*:

- **Máx. porções/dia** — ponha o total real que você usa por dia + 2 de margem.
  Isso é o que impede que uma falha, um duplo clique ou um comando repetido de
  Telegram entupam o aquário de comida. Padrão: 10.
- **Máx. por vez** — 2 ou 3 é suficiente.
- **Intervalo mínimo** — 45 s evita clique duplo acidental.
- **Janela de recuperação** — 90 min. Se a luz voltar depois disso, o horário
  perdido é ignorado (melhor um jejum que uma dose fora de hora).

## Ração: o que funciona

| Tipo | Funciona? |
|---|---|
| Granulado / pellet até 3 mm | Sim, é o ideal |
| Micro pellet, ração de alevino | Sim |
| Flocos pequenos e secos | Geralmente sim |
| Flocos grandes | Amasse antes, senão trava |
| Ração úmida, liofilizado leve | Não use |

A rosca tem folga radial de 4 mm entre o núcleo e a parede — grãos maiores que
isso vão encravar. Se sua ração é grande e você não quer amassar, aumente
`auger_od`, `auger_core` e `auger_pitch` em `cad/common.scad` e reimprima rosca
e tubo (o resto continua igual).

## Umidade: o inimigo de verdade

Ração absorvendo umidade empedra e trava a rosca. Isso é o motivo nº 1 de
alimentador automático falhar em viagem.

- Sachê de **sílica gel** dentro do funil, sempre.
- Tampa fechada, sempre.
- Não encha o funil até a boca: ração velha no fundo é a que empedra. Encha o
  que der para 3–4 semanas.
- Se seu aquário é aberto e o ambiente é úmido, considere trocar a ração do
  funil antes de cada viagem.

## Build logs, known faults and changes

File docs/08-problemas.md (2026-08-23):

# 8. Quando dá problema

## Mecânica

**A rosca trava / range.**
Rebarba na hélice (lime), parafusos das metades apertados demais (desaperte e
alinhe pelo giro livre), ou grão de ração maior que a folga. Teste sem ração:
se gira livre vazia e trava cheia, é a ração.

**Sai muito mais ração que o programado.**
Ração fluindo por gravidade pelo canal. O tubo é horizontal justamente para
evitar isso — confira se a braçadeira não deixou o conjunto inclinado para
frente. Reduza também a folga: `radial_clear = 0.3` em `common.scad`.

**Sai pouco ou nada, mas o motor gira.**
Ração empedrada fazendo "ponte" na boca do funil. Bata de leve no funil: se
descer, é isso. Troque a ração, ponha sílica e considere aumentar
`ANTIJAM_STEPS` em `firmware/include/config.h`.

**Motor esquenta.**
Normal ficar morno. Se estiver quente, aumente os µs por passo (1300 → 2000) e
confira a fonte: 5 V com queda para 4,2 V faz o motor perder torque e esquentar.
As bobinas são desligadas quando o motor para — se estiver esquentando
*parado*, tem pino travado em nível alto: revise a fiação IN1..IN4.

**Motor vibra mas não gira.**
Fios do motor na ordem errada no ULN2003, ou dois pinos IN trocados. Teste
com *Manutenção → Avançar*: se ele "tremer" no lugar, troque IN3 com IN4.

## Eletrônica

**Resets aleatórios ao alimentar.**
Falta o capacitor de 470–1000 µF junto do ULN2003, fonte fraca, ou fio fino
demais. É o problema mais comum do projeto.

**A câmera não inicializa (`esp_camera_init 0x105`).**
Cabo flat mal encaixado ou invertido, ou pinagem errada para a sua placa.
Confira `firmware/include/camera_pins.h` contra o exemplo oficial do fabricante
da SUA placa. Sem PSRAM a câmera cai para 640×480 automaticamente.

**Imagem verde/listrada.**
Alimentação instável ou cabo flat comprido demais. Baixe a resolução em
*Ajustes → Câmera*.

## Rede

**Não acho o `aquafeeder.local`.**
mDNS não funciona em algumas redes e em Android antigo. Use o IP direto (aparece
no monitor serial ou na lista de dispositivos do roteador) e reserve o IP no DHCP.

**Vídeo travando / interface lenta com o vídeo ligado.**
Normal: o stream MJPEG consome quase toda a banda do Wi-Fi do ESP32. Use *Foto*
no dia a dia e ligue o vídeo só quando quiser olhar. O stream roda na porta 81
justamente para não travar a API.

**Wi-Fi cai e não volta.**
O firmware tenta reconectar a cada 15 s e reinicia sozinho após 10 min sem rede.
Se cai sempre, o sinal está ruim: aproxime o roteador ou use um repetidor.
Veja o `rssi` em `/api/status` — abaixo de −75 dBm é problema.

**Esqueci a senha da interface.**
Grave o firmware por USB de novo com a NVS apagada:
```bash
pio run -e freenove_s3_cam -t erase && pio run -e freenove_s3_cam -t upload
```
Isso apaga TODA a configuração (Wi-Fi, agenda, contadores).

## Agenda e horários

**Alimentou na hora errada.**
Fuso horário. Em *Ajustes*, `Fuso (TZ POSIX)` tem que ser `<-03>3` para o
Brasil. Confira o relógio na aba *Agora*: se mostrar "sem hora", o NTP não
sincronizou (sem internet, ou o roteador bloqueia UDP 123).

**Não alimentou no horário.**
Cheque nesta ordem: (1) o slot está marcado como ativo e com o dia da semana
certo; (2) o relógio está sincronizado; (3) o limite diário não foi atingido —
o *Histórico* e o log serial mostram "slot barrado: Limite diário atingido".

**Alimentou duas vezes.**
Não deveria acontecer: cada horário só dispara se a última refeição foi antes
dele. Se aconteceu, provavelmente foram dois slots em horários próximos, ou
alguém clicou no botão além da agenda — o *Histórico* mostra a origem de cada
refeição.

## Log serial

É a melhor ferramenta de diagnóstico:

```bash
cd firmware && pio device monitor
```

O que procurar:

```
[cfg] carregado (412 bytes)
[feeder] pronto. 1024 passos/porcao, 1300 us/passo, hoje=2
[cam] ok (psram=1, tam=2, q=12)
[wifi] ok  ip=192.168.0.42  rssi=-58 dBm
[web] http://aquafeeder.local (porta 80)
[tg] pronto, offset inicial 123456789
[agenda] slot 0 disparado (08:00)
[feeder] 2 porcao(oes) via agenda, graos=14, ok=1
```

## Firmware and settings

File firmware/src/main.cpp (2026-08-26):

// =====================================================================
//  AquaFeeder ESP32-S3
//  Alimentador de aquario com agenda, acionamento manual e camera.
//
//  Primeiro boot: nao ha Wi-Fi salvo -> sobe o modo AP
//    rede "AquaFeeder-xxxx", senha "aquafeeder", abra http://192.168.4.1
//    em Ajustes > Rede coloque seu Wi-Fi e salve (o aparelho reinicia).
// =====================================================================
#include <Arduino.h>
#include <WiFi.h>
#include <ESPmDNS.h>
#include <ArduinoOTA.h>

#include "config.h"
#include "settings.h"
#include "feeder.h"
#include "camera.h"
#include "webserver.h"
#include "telegram.h"
#include "mqtt.h"
#include "alexa.h"

static bool     apMode      = false;
static bool     onlineReady = false;   // ja rodou NTP + mDNS depois de conectar
static uint32_t lostSince   = 0;
static time_t   slotTried[MAX_SLOTS] = {0};

// Um evento de alimentacao vai para todos os canais de aviso
static void avisaTodos(uint8_t portions, const char *src, bool ok, uint16_t pulses) {
    tgNotifyFeed(portions, src, ok, pulses);
    mqttNotifyFeed(portions, src, ok, pulses);
}

// --------------------------------------------------------------------- hora
static bool timeOk() {
    time_t now = time(nullptr);
    struct tm tmv;
    localtime_r(&now, &tmv);
    return (tmv.tm_year + 1900) >= 2024;
}

// --------------------------------------------------------------------- rede
// Chamado sempre que o Wi-Fi conecta (no boot ou numa reconexao): liga NTP e mDNS.
static void wifiOnConnected() {
    Serial.printf("[wifi] ok  ip=%s  rssi=%d dBm\n",
                  WiFi.localIP().toString().c_str(), WiFi.RSSI());
    configTzTime(cfg.tz, DEF_NTP1, DEF_NTP2);
    MDNS.end();
    if (MDNS.begin(cfg.host)) {
        MDNS.addService("http", "tcp", HTTP_PORT);
        Serial.printf("[wifi] http://%s.local\n", cfg.host);
    }
    onlineReady = true;
}

static void startWifi() {
    WiFi.persistent(false);
    WiFi.mode(WIFI_STA);
    WiFi.setHostname(cfg.host);
    WiFi.setSleep(false);          // sem isso o stream MJPEG engasga

    // Nunca configurado -> sobe o modo AP so para a configuracao inicial.
    if (!strlen(cfg.ssid)) {
        WiFi.mode(WIFI_AP);
        char ssid[32];
        snprintf(ssid, sizeof(ssid), AP_SSID_PREFIX "%04X",
                 (uint16_t)(ESP.getEfuseMac() & 0xFFFF));
        WiFi.softAP(ssid, AP_PASSWORD);
        apMode = true;
        Serial.printf("[wifi] MODO CONFIGURACAO -> rede \"%s\" senha \"%s\"\n", ssid, AP_PASSWORD);
        Serial.println(F("[wifi] abra http://192.168.4.1 e configure em Ajustes > Rede"));
        return;
    }

    // Ja configurado -> tenta a rede salva. Se falhar (ex.: roteador ainda subindo
    // apos queda de luz), NAO vira roteador: segue tentando em segundo plano (loop)
    // e a agenda continua rodando offline com o relogio interno.
    Serial.printf("[wifi] conectando em \"%s\"", cfg.ssid);
    WiFi.begin(cfg.ssid, cfg.pass);
    uint32_t t0 = millis();
    while (WiFi.status() != WL_CONNECTED && millis() - t0 < WIFI_TIMEOUT_MS) {
        delay(250);
        Serial.print('.');
    }
    Serial.println();

    if (WiFi.status() == WL_CONNECTED)
        wifiOnConnected();
    else
        Serial.println(F("[wifi] sem rede no boot; sigo tentando e a agenda roda offline"));
}

// ---------------------------------------------------------------- agenda
static void schedTask(void *) {
    for (;;) {
        vTaskDelay(pdMS_TO_TICKS(15000));
        if (!timeOk() || feederBusy()) continue;

        time_t now = time(nullptr);
        struct tm tmv;
        localtime_r(&now, &tmv);

        for (int i = 0; i < MAX_SLOTS; i++) {
            Slot &s = cfg.slots[i];
            if (!s.en) continue;
            if (!(s.dow & (1 << tmv.tm_wday))) continue;

            struct tm st = tmv;
            st.tm_hour = s.h;
            st.tm_min  = s.m;
            st.tm_sec  = 0;
            time_t slotT = mktime(&st);

            if (slotT > now) continue;                              // ainda nao deu a hora
            if (now - slotT > (time_t)cfg.catchUpMin * 60) continue; // fora da janela
            if (feederLastFeed() >= slotT) continue;                 // ja comeu depois disso
            if (slotTried[i] == slotT) continue;                     // ja tentou este horario

            slotTried[i] = slotT;
            String err;
            if (feederRequest(s.portions, SRC_SCHED, err))
                Serial.printf("[agenda] slot %d disparado (%02u:%02u)\n", i, s.h, s.m);
            else
                Serial.printf("[agenda] slot %d barrado: %s\n", i, err.c_str());
            break;                                                  // um por ciclo
        }
    }
}

// ----------------------------------------------------------------- botao
#if PIN_BUTTON >= 0
static void buttonTask(void *) {
    pinMode(PIN_BUTTON, INPUT_PULLUP);
    for (;;) {
        if (digitalRead(PIN_BUTTON) == LOW) {
            uint32_t t0 = millis();
            while (digitalRead(PIN_BUTTON) == LOW && millis() - t0 < 4000)
                vTaskDelay(pdMS_TO_TICKS(20));
            uint32_t held = millis() - t0;
            if (held > 700 && held < 4000) {
                String err;
                if (feederRequest(1, SRC_BUTTON, err))
                    Serial.println(F("[botao] 1 porcao"));
                else
                    Serial.printf("[botao] barrado: %s\n", err.c_str());
            }
            vTaskDelay(pdMS_TO_TICKS(500));
        }
        vTaskDelay(pdMS_TO_TICKS(60));
    }
}
#endif

// ----------------------------------------------------------------- setup
void setup() {
    Serial.begin(115200);
    delay(400);
    Serial.printf("\n\n=== AquaFeeder %s ===\n", FW_VERSION);
    Serial.printf("[sys] chip=%s psram=%u KB flash=%u MB\n",
                  ESP.getChipModel(), ESP.getPsramSize() / 1024,
                  ESP.getFlashChipSize() / (1024 * 1024));

    settingsLoad();
    feederInit();
    feederOnDone(avisaTodos);

#if HAS_CAMERA
    if (!cameraInit())
        Serial.println(F("[cam] seguindo sem camera (confira o cabo flat e a placa)"));
#endif

    startWifi();
    webStart();
    tgBegin();
    mqttBegin();
    alexaBegin();

    ArduinoOTA.setHostname(cfg.host);
    if (strlen(cfg.uiPass)) ArduinoOTA.setPassword(cfg.uiPass);
    ArduinoOTA.onStart([]() { Serial.println(F("[ota] atualizando...")); });
    ArduinoOTA.begin();

    xTaskCreatePinnedToCore(schedTask, "agenda", 4096, nullptr, 2, nullptr, 1);
#if PIN_BUTTON >= 0
    xTaskCreatePinnedToCore(buttonTask, "botao", 2560, nullptr, 1, nullptr, 1);
#endif

    if (!strlen(cfg.uiPass))
        Serial.println(F("[aviso] interface SEM SENHA. Defina uma em Ajustes > Rede."));
    Serial.println(F("[sys] pronto."));
}

// ------------------------------------------------------------------ loop
void loop() {
    ArduinoOTA.handle();

    if (webRebootRequested()) {
        Serial.println(F("[sys] reiniciando por pedido da interface"));
        delay(700);
        ESP.restart();
    }

    // vigia o Wi-Fi: reconecta em segundo plano e, ao voltar, religa NTP/mDNS.
    // Um aparelho ja configurado nunca vira roteador -- so segue tentando a rede.
    static uint32_t lastCheck = 0;
    if (!apMode && millis() - lastCheck > 15000) {
        lastCheck = millis();
        if (WiFi.status() == WL_CONNECTED) {
            lostSince = 0;
            if (!onlineReady) wifiOnConnected();     // conectou agora (boot offline ou reconexao)
        } else {
            if (!lostSince) lostSince = millis();
            onlineReady = false;                     // refaz NTP/mDNS quando a rede voltar
            Serial.println(F("[wifi] sem rede, tentando reconectar"));
            WiFi.disconnect();
            WiFi.begin(cfg.ssid, cfg.pass);
            if (millis() - lostSince > 600000UL) {   // 10 min sem rede -> reinicia
                Serial.println(F("[wifi] sem rede ha 10 min, reiniciando"));
                delay(200);
                ESP.restart();
            }
        }
    }
    delay(50);
}

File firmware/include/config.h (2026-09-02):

// =====================================================================
//  AquaFeeder -- pinos, limites e valores padrao
// =====================================================================
#pragma once
#include <Arduino.h>

#define FW_VERSION "1.0.0"

// --------------------------------------------------------------- placa
#define BOARD_FREENOVE_S3_CAM 1
#define BOARD_XIAO_S3_SENSE   2
#define BOARD_S3_NO_CAMERA    3

#ifndef FEEDER_BOARD
  #define FEEDER_BOARD BOARD_FREENOVE_S3_CAM
#endif

#if FEEDER_BOARD == BOARD_FREENOVE_S3_CAM
  #define HAS_CAMERA        1
  #define PIN_IN1           1     // ULN2003 IN1
  #define PIN_IN2           2     // ULN2003 IN2
  #define PIN_IN3           41    // ULN2003 IN3
  #define PIN_IN4           42    // ULN2003 IN4
  #define PIN_BUTTON        0     // botao BOOT da placa (alimenta 1 porcao)
  #define PIN_FEED_SENSOR   21    // opcional: sensor optico na calha
  #define PIN_STATUS_LED    -1
#elif FEEDER_BOARD == BOARD_XIAO_S3_SENSE
  #define HAS_CAMERA        1
  #define PIN_IN1           1     // D0
  #define PIN_IN2           2     // D1
  #define PIN_IN3           3     // D2
  #define PIN_IN4           4     // D3
  #define PIN_BUTTON        -1    // XIAO nao expoe o BOOT
  #define PIN_FEED_SENSOR   5     // D4
  #define PIN_STATUS_LED    21    // LED interno (invertido)
  #define STATUS_LED_INVERT 1
#else
  #define HAS_CAMERA        0
  #define PIN_IN1           1
  #define PIN_IN2           2
  #define PIN_IN3           41
  #define PIN_IN4           42
  #define PIN_BUTTON        0
  #define PIN_FEED_SENSOR   21
  #define PIN_STATUS_LED    -1
#endif

#ifndef STATUS_LED_INVERT
  #define STATUS_LED_INVERT 0
#endif

// Driver STEP/DIR usa 3 dos 4 GPIOs do motor
#define PIN_STEP  PIN_IN1
#define PIN_DIR   PIN_IN2
#define PIN_EN    PIN_IN3   // ENABLE do A4988/DRV8825 e ativo em nivel BAIXO

// -------------------------------------------------------------- driver
// DRV_ULN2003: motor 28BYJ-48 de 5V com redutor, driver ULN2003 (4 fios)
// DRV_STEPDIR: NEMA 17 com A4988 / DRV8825 / TMC2208 (STEP-DIR-EN) + 12V
#define DRV_ULN2003 1
#define DRV_STEPDIR 2
#ifndef MOTOR_DRIVER
  #define MOTOR_DRIVER DRV_ULN2003
#endif

// Frequencia do clock da camera. 20 MHz e o padrao. Se voce ligou o OV2640
// na mao, com jumpers, e a imagem sai listrada/verde, caia para 10000000 --
// fio comprido em barramento paralelo de 20 MHz e a causa numero 1 disso.
#ifndef CAM_XCLK_HZ
  #define CAM_XCLK_HZ 20000000
#endif

// ------------------------------------------------------------ mecanica
#if MOTOR_DRIVER == DRV_STEPDIR
  // NEMA 17: 200 passos/volta. Deixe o driver em 1/8 de micropasso
  // (A4988: MS1=H MS2=H | DRV8825: M0=H M1=H | TMC2208: 1/8 por padrao)
  #define MICROSTEPS             8
  #define STEPS_PER_REV          (200 * MICROSTEPS)   // 1600
  #define DEF_STEPS_PER_PORTION  (STEPS_PER_REV / 4)  // 400 = 1/4 volta ~= 0,23 ml
  #define DEF_STEP_US            900    // us entre passos (velocidade de cruzeiro)
  #define ANTIJAM_STEPS          36     // re antes de dispensar (quebra ponte)
  #define UNJAM_STEPS            160    // re maior quando detecta entupimento
  // Rampa de aceleracao: parte devagar (RAMP_START_US) e acelera ate cfg.stepUs
  // ao longo de RAMP_STEPS passos (e desacelera no fim). Vence a inercia sem
  // travar/patinar no arranque. Se ainda travar, aumente RAMP_START_US.
  #define RAMP_STEPS             200    // passos de acel/desacel
  #define RAMP_START_US          3000   // us/passo no inicio (quanto maior, mais suave)
  // Destrava (anti-entupimento): vibra no inicio (SHAKE) e avanca em segmentos
  // com micro-recuos (o recuo e reposto no proximo avanco -> dose intacta).
  #define SHAKE_STEPS            40     // amplitude de cada tranco da vibracao (~0,9mm de arco)
  #define SHAKE_US               1400   // us/passo na vibracao (menor=mais rapido/punch, maior=mais torque)
  #define DISPENSE_SEGMENTS      4      // divide o avanco em N trechos (recua entre eles)
  #define DEF_SHAKE_CYCLES       4      // ciclos de vibracao antes de dispensar
#else
  // 28BYJ-48 em meio-passo: 4096 passos por volta do eixo de saida
  #define STEPS_PER_REV          4096
  #define DEF_STEPS_PER_PORTION  1024   // 1/4 de volta ~= 0,23 ml
  #define DEF_STEP_US            1300   // us por meio-passo (nao abaixe de 1000)
  #define ANTIJAM_STEPS          90
  #define UNJAM_STEPS            400
  // Destrava (anti-entupimento) -- ver comentario no bloco do NEMA17
  #define SHAKE_STEPS            80     // amplitude de cada tranco da vibracao (~1,2mm de arco)
  #define SHAKE_US               1200   // us por meio-passo na vibracao (nao abaixe de 1000)
  #define DISPENSE_SEGMENTS      4      // divide o avanco em N trechos (recua entre eles)
  #define DEF_SHAKE_CYCLES       4      // ciclos de vibracao antes de dispensar
#endif
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

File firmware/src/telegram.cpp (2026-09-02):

#include "telegram.h"
#include "settings.h"
#include "feeder.h"
#include "camera.h"
#include "webserver.h"
#include <WiFi.h>
#include <WiFiClientSecure.h>
#include <ArduinoJson.h>
#include "mbedtls/base64.h"
#if HAS_CAMERA
#include "esp_camera.h"
#endif

static const char *TG_HOST = "api.telegram.org";
static const int   TG_PORT = 443;
static int64_t     tgOffset = 0;
static bool        drained  = false;

bool tgEnabled() { return strlen(cfg.tgToken) > 4; }

// ------------------------------------------------------------------ helpers
// Abre TLS. Usamos setInsecure(): nao validamos o certificado do Telegram.
// Para um aparelho domestico que so FALA com api.telegram.org isso e um risco
// aceitavel (e o que praticamente todas as bibliotecas de bot fazem). Se
// quiser validar, cole o certificado raiz em TG_ROOT_CA e use setCACert().
static bool tgConnect(WiFiClientSecure &cli, uint32_t timeoutMs = 12000) {
    cli.setInsecure();
    cli.setTimeout(timeoutMs / 1000);
    return cli.connect(TG_HOST, TG_PORT, timeoutMs);
}

static bool skipHeaders(WiFiClientSecure &cli, uint32_t timeoutMs) {
    uint32_t t0 = millis();
    while (cli.connected() && millis() - t0 < timeoutMs) {
        String line = cli.readStringUntil('\n');
        if (line == "\r" || line.length() == 0) return true;
    }
    return false;
}

static bool tgPostJson(const char *method, const String &body, JsonDocument *out = nullptr,
                       JsonDocument *filter = nullptr, uint32_t timeoutMs = 12000) {
    if (!tgEnabled() || WiFi.status() != WL_CONNECTED) return false;
    WiFiClientSecure cli;
    if (!tgConnect(cli, timeoutMs)) {
        Serial.println(F("[tg] falha de conexao TLS"));
        return false;
    }
    String req;
    req.reserve(200 + body.length());
    req  = "POST /bot"; req += cfg.tgToken; req += "/"; req += method; req += " HTTP/1.1\r\n";
    req += "Host: "; req += TG_HOST; req += "\r\n";
    req += "Content-Type: application/json\r\n";
    req += "Content-Length: "; req += body.length(); req += "\r\n";
    req += "Connection: close\r\n\r\n";
    req += body;
    cli.print(req);

    bool ok = skipHeaders(cli, timeoutMs);
    if (ok && out) {
        DeserializationError e = filter
            ? deserializeJson(*out, cli, DeserializationOption::Filter(*filter))
            : deserializeJson(*out, cli);
        ok = (e == DeserializationError::Ok);
        if (!ok) Serial.printf("[tg] json: %s\n", e.c_str());
    }
    cli.stop();
    return ok;
}

static bool tgSend(const String &text) {
    if (!strlen(cfg.tgChat)) return false;
    JsonDocument d;
    d["chat_id"] = cfg.tgChat;
    d["text"]    = text;
    String body;
    serializeJson(d, body);
    return tgPostJson("sendMessage", body);
}

// Retrato dos ajustes OPERACIONAIS (sem rede/segredos) para o painel do
// Telegram pre-preencher os campos. Vai embutido no link do botao "Abrir
// painel" -- e o unico jeito de o Mini App (hospedado fora) LER o estado atual
// sem servidor nenhum. Mantido enxuto para o link nao ficar gigante.
static String cfgSnapshotJson() {
    JsonDocument d;
    d["stepsPerPortion"] = cfg.stepsPerPortion;
    d["stepUs"]          = cfg.stepUs;
    d["reverse"]         = cfg.reverse;
    d["sensorEnabled"]   = cfg.sensorEnabled;
    d["antiJam"]         = cfg.antiJam;
    d["shakeCycles"]     = cfg.shakeCycles;
    d["maxPerDay"]       = cfg.maxPerDay;
    d["maxPerRequest"]   = cfg.maxPerRequest;
    d["minIntervalS"]    = cfg.minIntervalS;
    d["catchUpMin"]      = cfg.catchUpMin;
    d["camVflip"]        = cfg.camVflip;
    d["camHmirror"]      = cfg.camHmirror;
    d["camSize"]         = cfg.camSize;
    d["camQuality"]      = cfg.camQuality;
    d["tgNotify"]        = cfg.tgNotify;
    d["alexaPortions"]   = cfg.alexaPortions;
    d["tz"]              = cfg.tz;
    d["hasCam"]          = HAS_CAMERA ? 1 : 0;
    JsonArray a = d["slots"].to<JsonArray>();
    for (int i = 0; i < MAX_SLOTS; i++) {
        JsonObject s = a.add<JsonObject>();
        s["en"]  = cfg.slots[i].en;
        s["h"]   = cfg.slots[i].h;
        s["m"]   = cfg.slots[i].m;
        s["dow"] = cfg.slots[i].dow;
        s["p"]   = cfg.slots[i].portions;
    }
    String out;
    serializeJson(d, out);
    return out;
}

// base64url (sem padding) do retrato -- seguro para colocar numa query string
static String cfgSnapshotB64() {
    String json = cfgSnapshotJson();
    size_t need = 0;
    mbedtls_base64_encode(nullptr, 0, &need,
                          (const unsigned char *)json.c_str(), json.length());
    char *buf = (char *)malloc(need + 1);
    if (!buf) return String();
    size_t olen = 0;
    String out;
    if (mbedtls_base64_encode((unsigned char *)buf, need + 1, &olen,
                              (const unsigned char *)json.c_str(), json.length()) == 0) {
        out.reserve(olen);
        for (size_t i = 0; i < olen; i++) {
            char ch = buf[i];
            if (ch == '+') ch = '-';
            else if (ch == '/') ch = '_';
            else if (ch == '=') continue;   // sem padding
            out += ch;
        }
    }
    free(buf);
    return out;
}
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

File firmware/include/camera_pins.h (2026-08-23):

// =====================================================================
//  AquaFeeder -- pinagem do modulo de camera por placa
// =====================================================================
#pragma once
#include "config.h"

#if FEEDER_BOARD == BOARD_FREENOVE_S3_CAM
  // Freenove ESP32-S3-WROOM CAM
  #define PWDN_GPIO_NUM   -1
  #define RESET_GPIO_NUM  -1
  #define XCLK_GPIO_NUM   15
  #define SIOD_GPIO_NUM    4
  #define SIOC_GPIO_NUM    5
  #define Y9_GPIO_NUM     16
  #define Y8_GPIO_NUM     17
  #define Y7_GPIO_NUM     18
  #define Y6_GPIO_NUM     12
  #define Y5_GPIO_NUM     10
  #define Y4_GPIO_NUM      8
  #define Y3_GPIO_NUM      9
  #define Y2_GPIO_NUM     11
  #define VSYNC_GPIO_NUM   6
  #define HREF_GPIO_NUM    7
  #define PCLK_GPIO_NUM   13

#elif FEEDER_BOARD == BOARD_XIAO_S3_SENSE
  // Seeed XIAO ESP32S3 Sense
  #define PWDN_GPIO_NUM   -1
  #define RESET_GPIO_NUM  -1
  #define XCLK_GPIO_NUM   10
  #define SIOD_GPIO_NUM   40
  #define SIOC_GPIO_NUM   39
  #define Y9_GPIO_NUM     48
  #define Y8_GPIO_NUM     11
  #define Y7_GPIO_NUM     12
  #define Y6_GPIO_NUM     14
  #define Y5_GPIO_NUM     16
  #define Y4_GPIO_NUM     18
  #define Y3_GPIO_NUM     17
  #define Y2_GPIO_NUM     15
  #define VSYNC_GPIO_NUM  38
  #define HREF_GPIO_NUM   47
  #define PCLK_GPIO_NUM   13
#endif

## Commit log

2026-08-23 AquaFeeder ESP32-S3: projeto completo
    Alimentador de aquario com rosca sem-fim impressa em 3D, agenda de horarios,
    acionamento manual, camera e controle por Telegram.
    - cad/ pecas parametricas em OpenSCAD (suporta 28BYJ-48 e NEMA 17)
    - stl/ STLs prontos, separados por motor
    - firmware/ ESP32-S3 (PlatformIO): interface web, API HTTP, MJPEG, OTA
    - docs/ guia de montagem, eletronica, calibracao e diagnostico
    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
    [assembly.scad, auger.scad, auger.stl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]
2026-08-23 NEMA 17 + DRV8825, funil sem suporte, STL em portugues
    - suporte a NEMA 17 (motor_type no CAD, MOTOR_DRIVER=2 no firmware)
    - esquemas eletricos em SVG no site (28BYJ/ULN2003 e NEMA17/DRV8825 + sensor)
    - corrige: DRV8825 nao tem pino VDD (a logica sai do VMOT)
    - funil redesenhado: chanfro de 40 graus sob o flange e sob o aro
    -> area de saliencia sem apoio caiu de 1832 para 34 mm2 (nao pede mais suporte)
    - folga radial do tubo 0.4 -> 0.6mm: engole a barriga do teto do furo impresso
    - STLs renomeados para portugues, separados por pasta de motor
    [assembly.scad, barrel.scad, barrel_a.stl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]
2026-08-23 Camera externa opcional (URL MJPEG/JPEG na interface)
    Para quem nao tem modulo OV2640: campo camExtUrl nos ajustes. Se preenchido, a
    aba Agora mostra essa imagem em vez da camera do ESP32. O navegador busca a URL
    direto, sem proxy no firmware.
2026-08-23 Encaixe do eixo NEMA 17: folga 0.15 -> 0.35mm e segundo parafuso de fixacao
    Furo vertical em FDM sai 0.1-0.3mm menor que o nominal: com 0.15 de folga o eixo
    de aco de 5mm nao entrava sem broca. Dois parafusos M3 a 90 graus permitem pegar
    o achatado do eixo (4.6mm) em qualquer posicao angular da rosca.
    [auger.scad, common.scad, peca_de_teste.stl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]
2026-08-23 Esquemas com as cores reais do cabo do motor + paleta padrao do projeto
    - os 4 fios driver->motor usam as cores do cabo que vem no NEMA 17
    (vermelho/preto/azul/verde), com o nome da cor escrito em cada fio
    - paleta padrao definida no <style> do SVG: vermelho=12V, laranja=5V,
    violeta=3V3, preto=GND, branco=STP, amarelo=DIR, ciano=EN, rosa=4o sinal
    - aviso novo: o vermelho e o preto do cabo do MOTOR nao sao alimentacao,
    sao pontas de bobina (ligar no +12V queima o driver)
    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
2026-08-23 CI no Azure DevOps + relatorio das pecas
    - azure-pipelines.yml: compila os 5 ambientes do firmware e renderiza todas as
    pecas no OpenSCAD; publica .bin e .stl como artefato
    - build.sh agora sai com codigo 1 se o OpenSCAD emitir error/warning (era o que
    faltava para a CI conseguir reprovar um erro de CAD)
    - cad/dims.py: dimensoes, volume e massa em PETG por peca, total por kit,
    e avisa se alguma peca nao cabe na mesa da K1 Max
    [bracadeira.stl, caixa_eletronica.stl, calha.stl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]
2026-08-23 MQTT, cabo do motor na ordem real e ajustes medidos na impressao
    MQTT (novo): o ESP32 conecta para FORA num broker e fica escutando <prefixo>/cmd.
    Topicos cmd/status/evento/online, com Last Will -- se o alimentador cair, o
    proprio broker publica online=0. Configuravel em Ajustes > MQTT, funciona com
    qualquer broker padrao. Nada de porta aberta no roteador.
    Medido na peca de teste impressa:
    - folga do encaixe do eixo 0.35 -> 0.25mm (0.35 saiu frouxo na K1 Max)
    - gabarito do eixo agora tem a MESMA profundidade da rosca (14 -> 20mm); com 14
    ele batia no fundo e dava a impressao de faltar encaixe
    Cabo do motor: as duas pontas tem ordem DIFERENTE (o cabo reordena de proposito
    para os pares fi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
    [common.scad, peca_de_teste.stl, rosca.stl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]
2026-08-23 Esquema: deixa explicito que o cabo reordena posicao, nao cor
    - chaves marcando cada par de bobina (2B+1B e 1A+2A)
    - nota de que o conector do lado do motor e chaveado: a unica decisao de fiacao
    esta no plugue do driver, que e o que o desenho mostra
    - verificado por geometria: zero sobreposicao de texto no bloco das bobinas
2026-08-23 Suporte a ESP32-S3-DevKitC-1 / YD-ESP32-S3 (N16R8)
    - 2 ambientes novos: devkitc_s3_n16r8 e devkitc_s3_n16r8_nema17
    (16 MB de flash, PSRAM octal de 8 MB, particao default_16MB)
    - placa nao tem conector de flat: documentada a ligacao manual do OV2640 nos
    14 pinos que o firmware ja usa, sem mexer em codigo
    - CAM_XCLK_HZ configuravel: com jumper comprido o barramento de 20 MHz gera
    imagem listrada; cair para 10 MHz resolve
    [camera.cpp, config.h]
2026-08-23 Ajusta hierarquia da secao do OV2640 e tabela de ambientes em docs/04
2026-08-23 Roteiro em 9 etapas e esquema do driver na ordem da serigrafia
    Roteiro (novo, docs/00-etapas.md + secao no site): ordem de execucao com teste
    objetivo no fim de cada etapa e barra de progresso salva no navegador. A camera
    e a etapa 9 de proposito -- e a unica parte que, se falhar, nao impede o
    alimentador de alimentar.
    Esquema do DRV8825 redesenhado com os pinos na MESMA ordem da serigrafia da
    placa (DIR em cima, VMOT embaixo), como o usuario tem na mao. Antes estava
    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
2026-08-24 Teste de encaixe automatico: achou 2 colisoes reais entre pecas
    O aviso de regiao flutuante do fatiador me fez olhar melhor e o problema era
    pior que impressao: peca que nao entra.
    cad/check.sh (novo): renderiza a intersecao de cada par de pecas na posicao de
    montagem e mede o volume. Zero = so contato (apoio, encaixe). Maior que zero =
    ocupam o mesmo espaco. Roda para os dois motores, e entrou na CI.
    Colisoes que ele achou e que eu corrigi:
    - orelhas do colar (levantadas 9mm para caber o chanfro do funil) atravessavam
    o proprio chanfro do funil. Desfeito: flange volta a apoiar direto no topo do
    colar. O funil passa a pedir suporte so embaixo do flange, o que e aceitavel.
    - calha batia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
    [barrel.scad, bracadeira.stl, bracket.scad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]
2026-08-25 Firmware: scan de Wi-Fi na config, indicador de segredo salvo + copiar, reconexao resiliente
    - /api/scan lista redes 2,4 GHz para escolher o SSID sem digitar
    - interface mostra 'salvo' nos campos secretos e permite copiar (via ?secrets=1)
    - aparelho ja configurado nunca cai no modo AP: segue tentando a rede em segundo plano e religa NTP/mDNS ao reconectar
2026-08-25 Docs/site: variante USB no ESP32 + 12V separado, botao de scan e reconexao
2026-08-26 Rosca NEMA17: encaixe em D pelo achatado + rebaixo para a cabeca do parafuso
    O encaixe do eixo era um cilindro redondo, entao o torque dependia so dos parafusos. Agora o furo acompanha o achatado do eixo (perfil em D com folga n17_socket_c) e a face plana pega o torque. Adiciona tambem rebaixo 4.7x1.9mm na boca dos furos de fixacao para a cabeca do parafuso ficar recolhida no cubo (senao raspava no furo do tubo). STL regerado.
    [auger.scad, common.scad, rosca.stl]
2026-08-26 Telegram: botoes + painel (Mini App) para comandar do celular
    Reply keyboard com botoes (Alimentar/Foto/Status/Agenda) e traducao de rotulo para comando, para acionar sem digitar. Novo comando /jog. Opcional: painel HTML (pasta painel/) que abre como Telegram Mini App e envia comandos via web_app_data -- interface bonita, tudo pelo Telegram, sem broker. URL do painel em TG_WEBAPP_URL (config.h). Doc de acesso remoto atualizada.
    [config.h, telegram.cpp]
2026-08-26 Motor NEMA17: rampa de aceleracao trapezoidal (resolve trava no arranque)
    runSteps parte devagar (RAMP_START_US) e acelera ate cfg.stepUs em RAMP_STEPS passos, desacelerando no fim. Vence a inercia do NEMA17 sem travar/patinar ao comecar sob carga. Vale para a dispensa e para o jog/manutencao.
    [config.h, feeder.cpp]
2026-08-26 Painel: define TG_WEBAPP_URL com a URL do GitHub Pages
    Ativa o botao 'Abrir painel' no teclado do Telegram apontando para o Mini App hospedado em github.io/alimentador/painel.
2026-08-26 Painel: nao bloquear envio por initData vazio (Web App de botao de teclado)
    Web Apps abertos por KeyboardButton vem com initData vazio, entao usar isso como trava barrava o sendData no celular (o painel 'nao fazia nada'). Agora tenta enviar sempre e detecta 'fora do Telegram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
2026-08-26 Rosca robusta para racao 6mm: nucleo 9mm, OD 24mm; tubo cresce junto
    O nucleo de 6mm quebrava na torcao e o canal (4mm) nao passava bolinha de 6mm. Agora: nucleo 6->9mm (~3.4x mais resistente), OD 14->24mm (canal 7.5mm), passo 9->16mm, aleta 1.6->2.4mm e mais encravad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
    [assembly.scad, auger.scad, bracadeira.stl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]
2026-08-26 Telegram: loga o motivo quando a API recusa o teclado
    tgSendKb passou a ler a resposta do sendMessage e imprime a 'description' de erro no serial. Foi o que permitiu descobrir que o /menu antigo era firmware desatualizado, e ajuda a diagnosticar problemas futuros de teclado/web_app.
    [telegram.cpp]
2026-08-26 Alexa: comando de voz "alimentar agora" via Sinric Pro
    Novo modulo alexa.cpp (task no core 0, WebSocket de saida pro Sinric Pro,
    mesmo padrao do Telegram/MQTT: sem servidor proprio). Dispositivo Switch:
    "ligar" alimenta e volta a "desligado" em 1,5 s (botao momentaneo). A frase
    exata "alimentar agora" vem de uma Rotina no app Alexa (ligar = alimentar).
    - platformio.ini: + sinricpro/SinricPro@^3.5.2 (usa ArduinoJson 7, sem conflito)
    - feeder: nova fonte SRC_ALEXA (aparece no log como "alexa")
    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
2026-08-26 Alexa: aplicar chaves na hora (reinicia ao salvar) + log do device no boot
    A task da Alexa so le as chaves no boot; salvar as chaves pelo painel nao
    reiniciava, entao a conexao com o Sinric Pro nunca subia e a Alexa dizia
    "nao esta respondendo". Agora colar qualquer chave da Alexa em Ajustes marca
    needReboot. O serial passa a logar o Device ID ao subir a task, para conferir
    que a chave persistiu.
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2026-09-02 Telegram: painel com configuracao operacional completa (Mini App)
    O Mini App agora edita todos os ajustes de operacao: dosagem (inclui o
    Destrava + ciclos), seguranca, camera, notificacoes/fuso e a agenda (8
    horarios). Sem servidor: o bot embute um retrato da config (base64url) no
    link do botao 'Abrir painel' p/ pre-preencher; o painel manda de volta via
    web_app_data (sendData) e o firmware aplica igual ao /api/config. Novo
    comando /reiniciar. WiFi/senhas/tokens continuam so na interface local.
    Correcao (achada na revisao): feederApplySensor() liga/desliga o sensor de
    graos na hora, sem reboot -- chamado apos salvar no Telegram e na web.
    Handler JSON do bot mais robusto ({...} + limite de t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
    [feeder.cpp, telegram.cpp, webserver.cpp]
